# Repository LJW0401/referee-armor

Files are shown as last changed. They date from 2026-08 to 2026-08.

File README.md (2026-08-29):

# armor

Armor module for robot accessories.

> 暂停开发一段时间，目前已经实现了灯光效果，击打检测待后续有空闲时间了再做。结构设计也有待优化，目前的结构还不适合做CNC。

## 仓库结构

- `firmware/esp32`：ESP32-C3 SuperMini 的 PlatformIO 固件工程。
- `armor.code-workspace`：VS Code 多根工作区入口，包含仓库根目录与 ESP32 固件工程。

## 开发环境

在 VS Code 中打开 `armor.code-workspace`，资源管理器会显示 `repository` 和
`esp32-firmware` 两个工作区。固件使用 **ESP32-C3 SuperMini**（ESP32-C3FN4，4 MB
Flash）；PlatformIO 采用兼容的 `esp32-c3-devkitm-1` 开发板定义和 Arduino 框架。

板载蓝色 LED 接在 GPIO8；`firmware/esp32/src/main.cpp` 是一个串口输出和 LED 闪烁的硬件自检程序。

1. 在 VS Code 安装 **PlatformIO IDE** 扩展，并打开 `armor.code-workspace`。
2. 用可传输数据的 USB 线连接开发板；首次上传时如无法自动进入下载模式，按住 **BOOT**，点击上传，出现连接提示后松开。
3. 在 PlatformIO 的环境 `esp32-c3-supermini` 中执行 Upload，再打开串口监视器（115200 baud）。

配置启用了 ESP32-C3 原生 USB CDC，因此程序日志通过开发板的 USB 串口输出，无需额外的 USB-TTL 转换器。

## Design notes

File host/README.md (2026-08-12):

# Armor 上位机

这是 ESP32 装甲模块的 Python 串口上位机。它实现
[`docs/serial-protocol.md`](../docs/serial-protocol.md) 中的握手与状态读取协议。

## 安装

在仓库根目录执行：

```powershell
python -m venv .venv
.venv\Scripts\python -m pip install -e host
```

## 使用

先列出可选串口：

```powershell
.venv\Scripts\armor-host ports
```

选择 ESP32 所在端口并连接，例如：

```powershell
.venv\Scripts\armor-host connect --port COM5
```

命令只有在完整握手（序列号、随机数、CRC 和协议版本均匹配）后才报告连接成功，并立即输出一次状态。持续刷新状态：

```powershell
.venv\Scripts\armor-host connect --port COM5 --watch
```

烧录固件前应先退出该程序，避免占用 USB CDC 串口。

## 浏览器界面

启动仅绑定本机的 Web 服务：

```powershell
.venv\Scripts\armor-host serve
```

浏览器打开 <http://127.0.0.1:8080>。页面会列出串口；选择端口并点击“连接 ESP32”后，后端完成协议握手、读取一次状态，并每秒刷新一次。Web 服务不开放到局域网，因为该接口可控制本机串口。

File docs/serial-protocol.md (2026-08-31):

# ESP32 装甲模块串口通信协议

本文定义 PC 上位机与 ESP32-C3 下位机之间的 USB CDC 串口协议。它是协议的唯一规范；固件和上位机必须以本文为准实现。

## 目标与边界

- 上位机在用户选择串口后，以一次可关联的握手确认目标设备，再读取当前状态。
- 支持后续增加 LED 控制、去皮和标定命令，而不改变已有帧格式。
- 协议只运行在 ESP32-C3 原生 USB CDC 的 `Serial` 上，不涉及下载器私有协议。
- 本协议不提供认证或加密；USB 接入者拥有设备控制权限。

## 串口与会话

串口参数固定为 `115200 8N1`，无流控。ESP32 重启或固件更新后，USB 设备可能重新枚举，上位机必须将其视为断开连接。

固件的该串口只能输出本协议帧，禁止混入 `Serial.print` 日志或调试文本。调试日志必须关闭或使用其他接口，否则上位机无法可靠分帧。

上位机打开端口后应等待 500 ms、丢弃期间收到的字节，然后发送 `GET_DEVICE_INFO`。这个命令是幂等的：若 500 ms 内没有收到合法响应，上位机最多再发送两次；三次都失败即连接失败。写操作不得自动重试。

一次连接中的请求必须串行：在收到当前请求的成功或错误响应前，不得发送下一请求。下位机必须在 200 ms 内响应可立即完成的查询命令；需要更久时间的将来命令应使用异步任务模型，而非阻塞串口处理。

## 帧编码

每帧先生成“原始帧”，以 Consistent Overhead Byte Stuffing（COBS）编码，再追加单个 `0x00` 作为帧结束符。空帧（连续两个 `0x00`）必须丢弃。

COBS 解码后的原始帧采用小端字节序：

| 偏移 | 字段 | 类型 | 说明 |
| --- | --- | --- | --- |
| 0 | `version` | `u8` | 协议版本，当前固定为 `1` |
| 1 | `type` | `u8` | 帧类型 |
| 2 | `sequence` | `u16` | 上位机递增请求序号；响应必须原样回显 |
| 4 | `payload_length` | `u16` | 负载长度，范围 `0..192` |
| 6 | `payload` | bytes | 命令或响应数据 |
| 6 + N | `crc16` | `u16` | 前述所有字节的 CRC，不包含自身 |

CRC 使用 **CRC-16/CCITT-FALSE**：多项式 `0x1021`、初值 `0xFFFF`、不反射输入输出、结果异或 `0x0000`。`payload_length` 与实际长度不符、版本不支持、COBS 解码失败、CRC 不匹配或原始帧超过 200 字节时，接收方必须丢弃该帧；不能执行其中的命令。

`sequence` 从 `1` 开始递增，到 `65535` 后回绕为 `1`；`0` 保留。上位机只接受与未完成请求具有相同 `sequence` 的响应。任何不匹配的响应都必须丢弃并记录为协议错误。

## 帧类型与命令

请求帧 `type` 为命令号；成功响应为 `命令号 | 0x80`；错误响应为 `0xFF`。本版本定义如下：

| 请求 | 成功响应 | 名称 | 负载 |
| --- | --- | --- | --- |
| `0x01` | `0x81` | `GET_DEVICE_INFO` | 请求携带上位机随机数；响应携带设备身份 |
| `0x02` | `0x82` | `GET_STATUS` | 请求为空；响应携带当前运行状态 |
| `0x10` | `0x90` | `SET_LED_COLOR` | 请求携带同一颜色的 RGB 值；响应为空 |
| `0x11` | `0x91` | `SET_LED_EFFECT` | 设置静态或独立随机呼吸灯效果；响应为空 |

尚未定义的命令号必须返回错误 `UNSUPPORTED_COMMAND`，不得静默忽略。

### `GET_DEVICE_INFO`（建立连接）

请求负载固定为 4 字节 `client_nonce`（`u32`）。上位机每次打开端口必须生成新的随机值。

成功响应负载：

| 偏移 | 字段 | 类型 | 说明 |
| --- | --- | --- | --- |
| 0 | `client_nonce` | `u32` | 必须等于请求值 |
| 4 | `device_id` | `u64` | 芯片 MAC 转为无符号 64 位值；全局唯一设备标识 |
| 12 | `protocol_version` | `u8` | 当前为 `1` |
| 13 | `firmware_major` | `u8` | 固件主版本 |
| 14 | `firmware_minor` | `u8` | 固件次版本 |
| 15 | `firmware_patch` | `u8` | 固件补丁版本 |
| 16 | `capabilities` | `u32` | 支持能力位图 |

仅当响应 `sequence`、帧类型、`client_nonce` 和 `protocol_version` 均匹配时，上位机才可标记为“已连接到 ESP32”。`device_id` 用于在 UI 中识别曾连接过的设备，不能仅依赖易变化的 COM 端口号。

能力位定义：`bit 0` = 支持 WS2812 控制，`bit 1` = 支持 HX711，`bit 2` = 支持去皮，`bit 3` = 支持重量标定。未声明的位必须为 `0`。

### `GET_STATUS`

仅在握手成功后允许发送。请求负载长度为 `0`。

成功响应负载固定为 24 字节：

| 偏移 | 字段 | 类型 | 说明 |
| --- | --- | --- | --- |
| 0 | `status_schema` | `u8` | 当前固定为 `2` |
| 1 | `health_flags` | `u16` | 设备健康与可用性位图 |
| 3 | `uptime_ms` | `u32` | 本次启动后毫秒数，允许回绕 |
| 7 | `weight_mg` | `i32` | 已滤波净重，单位毫克；无有效值时为 `INT32_MIN` |
| 11 | `sample_age_ms` | `u32` | 最新有效 HX711 样本距当前的时长；无有效样本时为 `UINT32_MAX` |
| 15 | `led_count` | `u8` | 已配置的 WS2812 灯珠数，未配置为 `0` |
| 16 | `active_led_effect` | `u8` | 当前灯效编号，`0` 表示关闭/静态 |
| 17 | `led_red` | `u8` | 左右 WS2812 灯条当前共用颜色的红色分量 |
| 18 | `led_green` | `u8` | 左右 WS2812 灯条当前共用颜色的绿色分量 |
| 19 | `led_blue` | `u8` | 左右 WS2812 灯条当前共用颜色的蓝色分量 |
| 20 | `led_brightness_percent` | `u8` | RGB 比例对应的共同亮度，范围 `0..100` |
| 21 | `reserved` | 3 bytes | 当前必须为 `0`，接收方忽略 |

`health_flags`：`bit 0` = HX711 已初始化，`bit 1` = 已取得有效重量，`bit 2` = HX711 读取超时，`bit 3` = 已完成去皮，`bit 4` = WS2812 已初始化，`bit 5` = 重量标定参数有效，`bit 6` = LED 配置 NVS 持久化可用。未定义位必须为 `0`。

上位机应在建立连接后立即请求一次状态；连续刷新频率不得高于 10 Hz。若 `sample_age_ms` 大于 1000 ms，或设置了 HX711 读取超时位，UI 必须明确显示重量数据已过期/故障，不能将旧值显示为实时重量。

### `SET_LED_COLOR`

仅在握手成功后允许发送。请求负载固定为 4 字节，依次为 `red`、`green`、`blue`（定义 RGB 比例，均为 `u8`，范围 `0..255`）和 `brightness_percent`（`u8`，范围 `0..100`）。成功响应负载长度为 `0`。

该命令始终将相同的颜色写入左右两个灯条：左灯条连接 GPIO0、右灯条连接 GPIO1，每条均为 8 颗 WS2812。上位机默认提供蓝色 `#0000FF`、红色 `#FF0000` 与标准紫色 `#800080` 三个预设，也可发送任意自定义 RGB 值；协议不支持为左右灯条设置不同颜色。

设备首次运行或未找到有效颜色配置时默认显示标准紫色 `#800080`、亮度 `100%`。每次 `SET_LED_COLOR` 成功后，设备将 RGB 比例和亮度写入 NVS；后续重启会恢复。固件先按最大 RGB 分量归一化颜色比例、再按亮度缩放、最后以 γ=2.2 输出 WS2812 PWM，因此调节亮度不会改变色相；状态与上位机始终显示未校正的原始比例和亮度。若 NVS 无法访问或写入，状态的 LED 持久化位会清除，且 `SET_LED_COLOR` 返回 `INTERNAL_ERROR`，不会报告设置成功。

### `SET_LED_EFFECT`

仅在握手成功后允许发送。请求负载固定为 1 字节 `effect`：`0` 为静态颜色，`1` 为独立随机呼吸灯；成功响应负载长度为 `0`。设置静态 RGB 颜色会自动切回效果 `0`。灯效选择会写入 NVS，设备重启后恢复最后选择的灯效。

效果 `1` 中的 16 颗 WS2812（左右各 8 颗）各自使用独立的随机初始相位、1800–4000 ms 周期及颜色序列。在单颗灯珠呼吸周期的 55% 处开始向下一随机颜色交叉淡化，此时当前颜色尚未完全变暗，满足连续叠加的换色效果。设备保存的是效果选择；每次启动时会重新随机生成呼吸灯的初始相位、周期及颜色序列。

## 错误响应

错误帧 `type=0xFF`，并使用原请求的 `sequence`。负载为：

| 偏移 | 字段 | 类型 | 说明 |
| --- | --- | --- | --- |
| 0 | `command` | `u8` | 引发错误的请求命令号 |
| 1 | `error_code` | `u8` | 错误码 |

错误码：

| 值 | 名称 | 含义 |
| --- | --- | --- |
| `0x01` | `UNSUPPORTED_VERSION` | 不支持请求的协议版本 |
| `0x02` | `UNSUPPORTED_COMMAND` | 命令未定义 |
| `0x03` | `INVALID_PAYLOAD` | 负载长度或字段非法 |
| `0x04` | `NOT_CONNECTED` | 需握手的命令在握手前调用 |
| `0x05` | `BUSY` | 下位机无法在协议时限内接收该操作 |
| `0x06` | `INTERNAL_ERROR` | 下位机内部故障；固件须记录具体原因 |

无效帧本身没有可信 `sequence`，不得尝试构造错误响应。

## 上位机连接流程

```text
选择串口 → 打开 115200 8N1 → 等待并清空输入
        → GET_DEVICE_INFO(sequence, client_nonce)
        → 校验 0x81、sequence、nonce、CRC 和协议版本
        → 标记已连接并显示 device_id / 固件版本 / capabilities
        → GET_STATUS(sequence + 1) → 校验 0x82 → 显示状态
```

任何读取超时、端口 I/O 错误、解码错误或响应关联失败都会使本次请求失败。连续两次状态请求失败时，上位机必须断开并要求用户重新选择/连接，而不是继续展示过期状态。

## 实现与测试要求

- 固件和上位机各自必须有 COBS、CRC、长度限制、帧关联和错误帧的单元测试。
- 集成测试至少覆盖：正常握手、错误 `sequence`、错误 `client_nonce`、CRC 损坏、截断帧、未知命令，以及 HX711 无有效样本的状态响应。
- 上位机在 UI 中显示的连接成功必须来自完成的协议握手，不能由“成功打开 COM 端口”替代。

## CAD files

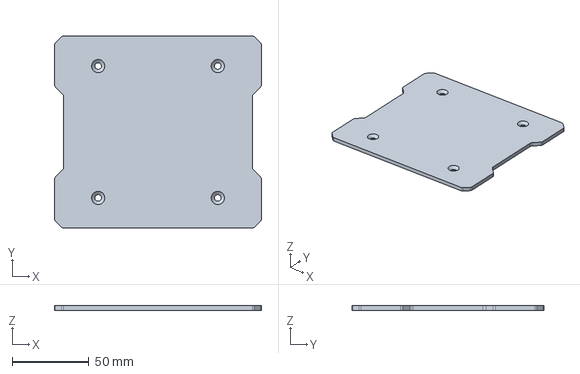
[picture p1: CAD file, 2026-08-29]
hardware/mechanical/装甲板表面.step
135.0 x 125.0 x 3.00 mm

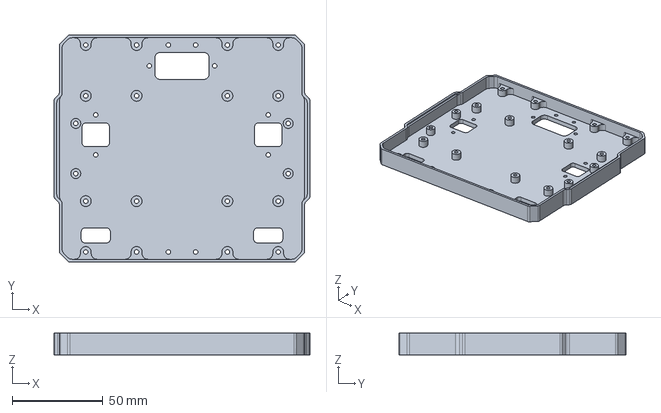
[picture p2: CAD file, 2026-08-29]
hardware/mechanical/装甲板底座.step
141.0 x 125.0 x 12.0 mm

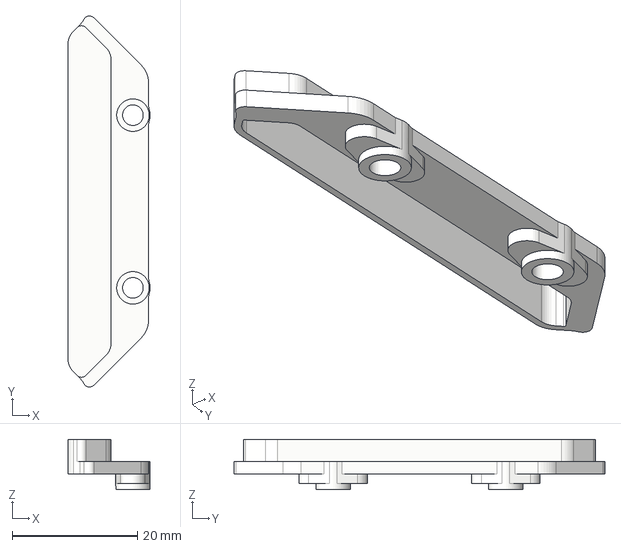
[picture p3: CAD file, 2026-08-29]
hardware/mechanical/灯条柔光块.step
13.2 x 59.3 x 8.00 mm

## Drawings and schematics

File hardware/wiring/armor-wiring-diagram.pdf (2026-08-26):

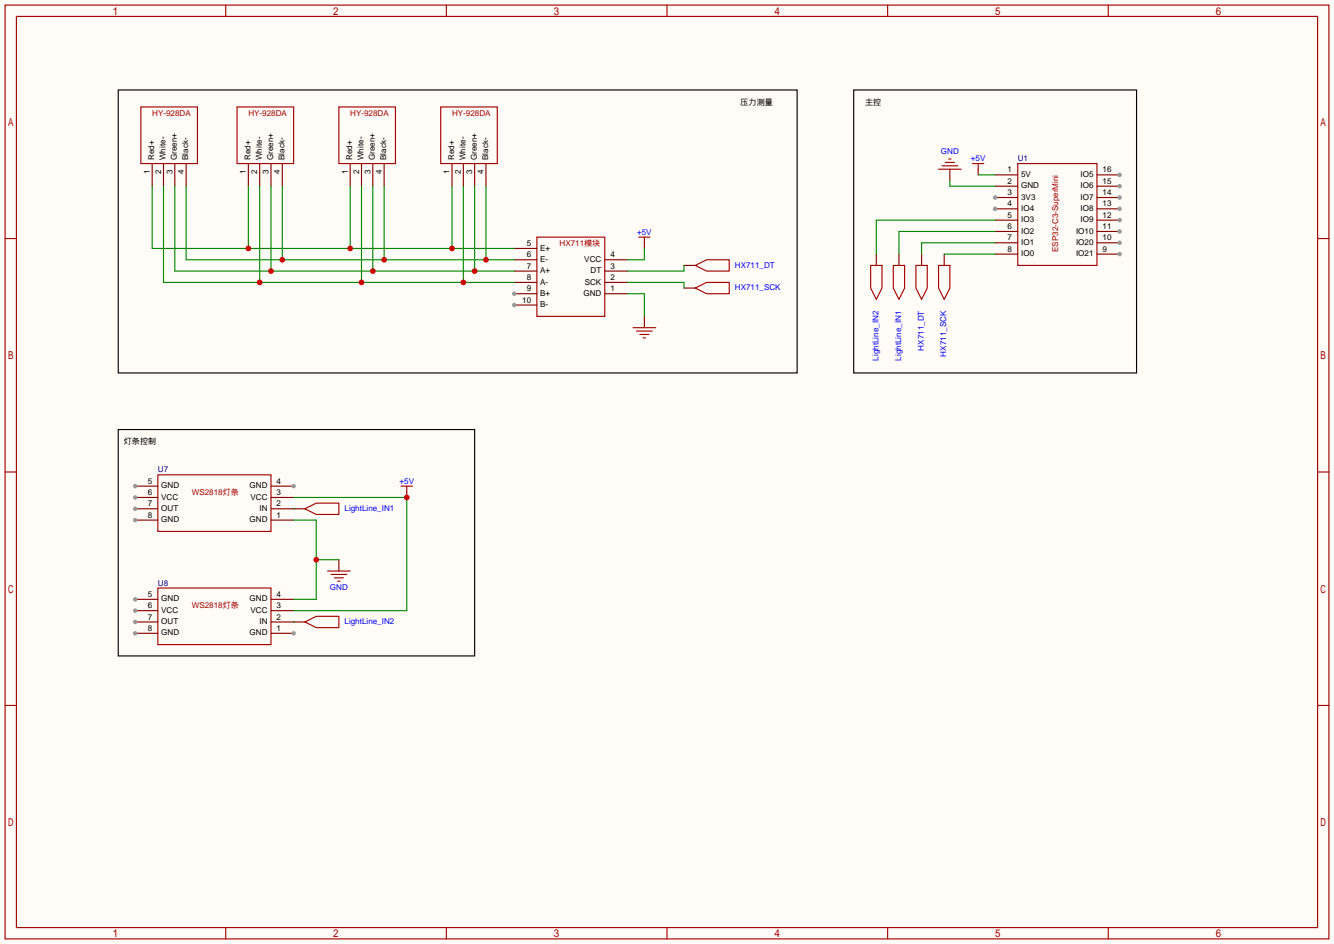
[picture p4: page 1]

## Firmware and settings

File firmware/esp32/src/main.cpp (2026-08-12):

/**
 * @file main.cpp
 * @brief Application entry point that exposes the armor USB CDC protocol.
 */

#include <Arduino.h>

#include "serial_protocol.h"

namespace {
armor::led::Controller led_controller;
armor::serial_protocol::Endpoint serial_endpoint(led_controller);
}

void setup() {
  Serial.begin(115200);
  led_controller.begin();
  serial_endpoint.begin(Serial);
}

void loop() {
  serial_endpoint.poll();
  led_controller.tick(millis());
}

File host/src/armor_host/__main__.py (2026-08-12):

"""Command-line entry point for listing, connecting to, and monitoring armor."""

from __future__ import annotations

import argparse
from dataclasses import asdict
import json
import sys
import time

from .client import ArmorClient, ConnectionError, list_serial_ports
from .server import serve


def build_parser() -> argparse.ArgumentParser:
    """Build the bounded command-line interface."""

    parser = argparse.ArgumentParser(prog="armor-host")
    commands = parser.add_subparsers(dest="command", required=True)
    commands.add_parser("ports", help="list selectable serial ports")
    connect = commands.add_parser("connect", help="handshake with one ESP32")
    connect.add_argument("--port", required=True, help="serial port, for example COM5")
    connect.add_argument(
        "--watch", action="store_true", help="refresh status at 10 Hz until Ctrl+C"
    )
    serve_command = commands.add_parser("serve", help="start the local browser interface")
    serve_command.add_argument("--port", type=int, default=8080, help="localhost HTTP port")
    return parser


def main() -> int:
    """Run the selected host command and return a process exit status."""

    arguments = build_parser().parse_args()
    if arguments.command == "ports":
        print(json.dumps([asdict(port) for port in list_serial_ports()], ensure_ascii=False, indent=2))
        return 0
    if arguments.command == "serve":
        if not 1 <= arguments.port <= 65535:
            parser = build_parser()
            parser.error("--port must be in the range 1..65535")
        serve(arguments.port)

    try:
        with ArmorClient.open(arguments.port) as client:
            device = client.connect()
            print(json.dumps({"connected": device.to_dict()}, ensure_ascii=False))
            while True:
                print(json.dumps({"status": client.get_status().to_dict()}, ensure_ascii=False))
                if not arguments.watch:
                    return 0
                time.sleep(0.1)
    except ConnectionError as error:
        print(f"armor-host: {error}", file=sys.stderr)
        return 1
    except KeyboardInterrupt:
        return 0


if __name__ == "__main__":
    raise SystemExit(main())

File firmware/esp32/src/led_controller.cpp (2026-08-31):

/**
 * @file led_controller.cpp
 * @brief WS2812 driver for left GPIO0 and right GPIO1 light strips.
 */

#include "led_controller.h"

#include <Adafruit_NeoPixel.h>
#include <esp_system.h>
#include <math.h>
#include <Preferences.h>

namespace armor::led {
namespace {

constexpr uint8_t kPixelsPerStrip = 8;
constexpr uint8_t kLeftStripPin = 0;
constexpr uint8_t kRightStripPin = 1;
constexpr neoPixelType kPixelType = NEO_GRB + NEO_KHZ800;
constexpr char kPreferencesNamespace[] = "armor-led";
constexpr char kColorKey[] = "rgb";
constexpr char kBrightnessKey[] = "brightness";
constexpr char kEffectKey[] = "effect";
constexpr uint32_t kColorMask = 0x00FFFFFF;
constexpr RgbColor kDefaultColor{128, 0, 128};
constexpr uint8_t kDefaultBrightnessPercent = 100;
constexpr float kSrgbGamma = 2.2F;
constexpr uint8_t kTotalPixels = kPixelsPerStrip * 2;
constexpr uint16_t kBreathingPeriodMinimumMs = 1800;
constexpr uint16_t kBreathingPeriodMaximumMs = 4000;
constexpr uint8_t kTransitionStartPercent = 55;
constexpr uint16_t kFrameIntervalMs = 25;

Adafruit_NeoPixel left_strip(kPixelsPerStrip, kLeftStripPin, kPixelType);
Adafruit_NeoPixel right_strip(kPixelsPerStrip, kRightStripPin, kPixelType);

struct BreathingPixel {
  RgbColor current;
  RgbColor next;
  uint32_t cycle_started_ms;
  uint16_t period_ms;
};

BreathingPixel breathing_pixels[kTotalPixels]{};
uint32_t last_breathing_frame_ms = 0;

void fill_strip(Adafruit_NeoPixel& strip, uint32_t packed_color) {
  for (uint8_t pixel = 0; pixel < kPixelsPerStrip; ++pixel) {
    strip.setPixelColor(pixel, packed_color);
  }
}

uint8_t srgb_to_led_pwm(uint8_t component) {
  const float normalized = static_cast<float>(component) / 255.0F;
  return static_cast<uint8_t>(roundf(powf(normalized, kSrgbGamma) * 255.0F));
}

uint8_t scaled_component(uint8_t component, uint8_t maximum_component,
                         uint8_t brightness_percent) {
  if (maximum_component == 0 || brightness_percent == 0) {
    return 0;
  }
  const float ratio = static_cast<float>(component) / maximum_component;
  return static_cast<uint8_t>(roundf(ratio * brightness_percent * 2.55F));
}

uint32_t corrected_color(const RgbColor& color, uint8_t brightness_percent) {
  const uint8_t maximum_component = max(color.red, max(color.green, color.blue));
  return left_strip.Color(
      srgb_to_led_pwm(scaled_component(color.red, maximum_component, brightness_percent)),
      srgb_to_led_pwm(scaled_component(color.green, maximum_component, brightness_percent)),
      srgb_to_led_pwm(scaled_component(color.blue, maximum_component, brightness_percent)));
}

RgbColor random_color() {
  return {static_cast<uint8_t>(random(32, 256)),
          static_cast<uint8_t>(random(32, 256)),
          static_cast<uint8_t>(random(32, 256))};
}

uint16_t random_period_ms() {
  return static_cast<uint16_t>(
      random(kBreathingPeriodMinimumMs, kBreathingPeriodMaximumMs + 1));
}

RgbColor interpolate(RgbColor first, RgbColor second, float amount) {
  return {
      static_cast<uint8_t>(roundf(first.red + (second.red - first.red) * amount)),
      static_cast<uint8_t>(roundf(first.green + (second.green - first.green) * amount)),
      static_cast<uint8_t>(roundf(first.blue + (second.blue - first.blue) * amount)),
  };
}

void set_physical_pixel(uint8_t index, uint32_t packed_color) {
  if (index < kPixelsPerStrip) {
    left_strip.setPixelColor(index, packed_color);
    return;
  }
  right_strip.setPixelColor(index - kPixelsPerStrip, packed_color);
}

}  // namespace

void Controller::begin() {
  left_strip.begin();
  right_strip.begin();
  initialized_ = true;
  persistence_healthy_ = load_configuration();
  if (effect_ == Effect::kRandomBreathing) {
    initialize_breathing(millis());
  } else {
    render_static_color();
  }
}

bool Controller::set_color(RgbColor color, uint8_t brightness_percent) {
  if (!initialized_ || !persistence_healthy_ || brightness_percent > 100 ||
      !save_configuration(color, brightness_percent, Effect::kStatic)) {
    persistence_healthy_ = false;
    return false;
  }
  color_ = color;
  brightness_percent_ = brightness_percent;
  effect_ = Effect::kStatic;
  render_static_color();
  return true;
}

bool Controller::set_effect(Effect effect) {
  if (!initialized_ || !persistence_healthy_ ||
      static_cast<uint8_t>(effect) >
          static_cast<uint8_t>(Effect::kRandomBreathing) ||
      !save_configuration(color_, brightness_percent_, effect)) {
    persistence_healthy_ = false;
    return false;
  }
  effect_ = effect;
  if (effect_ == Effect::kStatic) {
    render_static_color();
  } else {
    initialize_breathing(millis());
  }
  return true;
}

void Controller::tick(uint32_t now_ms) {
  if (effect_ == Effect::kRandomBreathing) {
    render_breathing(now_ms);
  }
}

void Controller::render_static_color() {
  const uint32_t packed_color = corrected_color(color_, brightness_percent_);
  fill_strip(left_strip, packed_color);
  fill_strip(right_strip, packed_color);
  left_strip.show();
  right_strip.show();
}

RgbColor Controller::color() const { return color_; }

uint8_t Controller::brightness_percent() const { return brightness_percent_; }

Effect Controller::effect() const { return effect_; }

bool Controller::is_initialized() const { return initialized_; }

bool Controller::is_persistence_healthy() const { return persistence_healthy_; }

bool Controller::load_configuration() {
  Preferences preferences;
  // Open read-write on first boot so the namespace is ready for later LED
  // configuration commands.
  if (!preferences.begin(kPreferencesNamespace, false)) {
    color_ = kDefaultColor;
    brightness_percent_ = kDefaultBrightnessPercent;
    effect_ = Effect::kStatic;
    return false;
  }
  const uint32_t packed_color = preferences.getUInt(kColorKey, kColorMask + 1);
  const uint8_t stored_brightness =
      preferences.getUChar(kBrightnessKey, kDefaultBrightnessPercent);
  const uint8_t stored_effect =
      preferences.getUChar(kEffectKey, static_cast<uint8_t>(Effect::kStatic));
  preferences.end();
  if (packed_color > kColorMask) {
    color_ = kDefaultColor;
    brightness_percent_ = kDefaultBrightnessPercent;
    effect_ = Effect::kStatic;
    return true;
  }
  color_ = {
      static_cast<uint8_t>(packed_color >> 16),
      static_cast<uint8_t>(packed_color >> 8),
      static_cast<uint8_t>(packed_color),
  };
  brightness_percent_ = stored_brightness;
  if (brightness_percent_ > 100 ||
      stored_effect > static_cast<uint8_t>(Effect::kRandomBreathing)) {
    color_ = kDefaultColor;
    brightness_percent_ = kDefaultBrightnessPercent;
    effect_ = Effect::kStatic;
    return true;
  }
  effect_ = static_cast<Effect>(stored_effect);
  return true;
}
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

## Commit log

2026-08-09 添加功能完成后自动提交规则
    新增仓库协作规则，要求每完成一个独立功能后立即创建 Git 提交。
2026-08-09 补充提交编码校验规则
    要求使用 UTF-8 文件传递包含非 ASCII 字符的提交信息，并在提交后验证编码。
2026-08-09 初始化 ESP32-C3 开发环境
    添加 PlatformIO 配置、硬件自检程序、忽略规则、编辑器扩展建议及开发说明。
2026-08-09 重组固件目录并添加多根工作区
    将 ESP32 PlatformIO 工程移至 firmware/esp32，并添加包含仓库与固件工程的 VS Code 工作区入口。
2026-08-09 补充固件工程本地配置
    为嵌套的 PlatformIO 固件工程添加本地忽略规则和编辑器扩展建议。
2026-08-12 定义上位机串口通信协议
    新增 ESP32 USB CDC 协议规范，定义握手、状态读取、COBS 分帧、CRC 校验和错误处理。
2026-08-12 实现 ESP32 串口协议端点
    添加 COBS 与 CRC 校验的 USB CDC 协议处理，支持设备握手和真实可用状态查询。
2026-08-12 构建串口上位机客户端
    新增 Python 上位机，可列出串口、校验握手并读取 ESP32 状态，附带协议和连接单元测试。
2026-08-12 忽略上位机安装元数据
    将可编辑安装生成的 Python egg-info 元数据排除在版本控制之外。
2026-08-12 添加上位机浏览器控制界面
    新增本地 Web 服务和可视化页面，用于选择串口、协议握手、显示设备身份并刷新状态。
2026-08-12 实现双侧 WS2812 灯光控制
    支持 GPIO0 和 GPIO21 上各八颗灯珠同步显示，提供蓝红紫预设和上位机自定义 RGB 设置。
2026-08-12 持久化双侧灯条颜色设置
    首次运行默认显示紫色，并将成功设置的 RGB 颜色保存至 NVS 以便重启恢复。
2026-08-12 修复首次启动灯光颜色保存
    首次读取颜色配置时以可写方式创建 NVS 命名空间，避免首次设置颜色被错误拒绝。
    [led_controller.cpp]
2026-08-12 使用 RGB 滑块设置自定义灯光颜色
    将浏览器自定义取色器改为红绿蓝三个 0 至 255 滑块，并显示实时颜色预览。
2026-08-12 连接时同步灯光颜色滑块
    在状态响应中携带当前 RGB 颜色，使上位机连接后从设备同步三个颜色滑块。
2026-08-12 仅在连接时同步灯光颜色
    将 RGB 滑块同步限制为握手后的首次状态，避免后续状态刷新覆盖用户设置。
2026-08-12 校正 WS2812 颜色亮度输出
    在 WS2812 输出前应用 sRGB 伽马校正，使低亮度 RGB 值更接近浏览器预览效果。
2026-08-12 分离灯光 RGB 比例与亮度控制
    新增独立亮度滑块，固件保持 RGB 色相比例并持久化亮度和颜色设置。
2026-08-12 统一默认与预设为标准紫色
    将未设置时的双灯条颜色和上位机紫色预设调整为红蓝等比例的 #800080。
2026-08-12 发布上位机 0.2.0 版本
    更新上位机包版本，包含双侧 WS2812 灯光控制与浏览器 RGB 亮度设置。
2026-08-12 添加独立随机呼吸灯效果
    为 16 颗 WS2812 添加独立随机颜色、相位和周期的交叠呼吸效果，并提供上位机启用入口。
2026-08-12 发布上位机 0.2.1 补丁版本
    更新上位机包补丁版本，包含独立随机呼吸灯功能。
2026-08-26 添加装甲接线图
    新增装甲模块接线图 PDF，便于硬件装配和接线核对。
2026-08-28 调整右侧灯条输出引脚
    将右侧 WS2812 灯条由 GPIO21 调整为 GPIO1，并同步更新串口协议文档中的硬件连接说明。
2026-08-29 新增结构文件
    [灯条柔光块.step, 装甲板底座.step, 装甲板表面.step]
2026-08-29 添加声明
2026-08-31 持久化呼吸灯模式
    将灯效选择与颜色、亮度一同写入 NVS，并在设备启动时恢复保存的灯效。
    同步更新串口协议中的持久化行为说明。
2026-08-31 发布 0.2.2 版本
    同步更新上位机包版本与 ESP32 固件自报版本，为包含灯效持久化、接线调整和结构文件的 0.2.2 发布做准备。
